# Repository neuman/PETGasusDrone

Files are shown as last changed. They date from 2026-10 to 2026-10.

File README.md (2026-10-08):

# PETGasus

A small 3D-printed quadcopter for an adult and a kid to build together. It needs no soldering, prints in one piece in PETG, and flies by sight (no camera or goggles), mostly indoors.

**[See the design explained, with a 3D build-along →](https://neuman.github.io/PETGasusDrone/)**

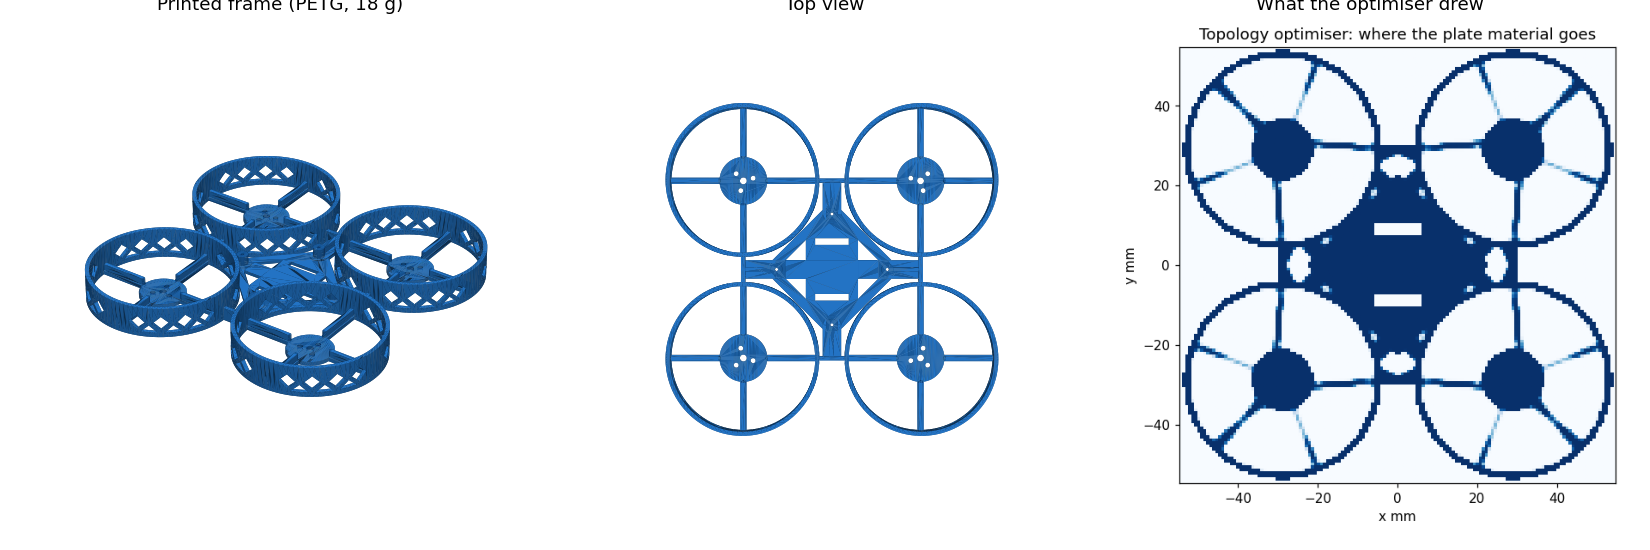
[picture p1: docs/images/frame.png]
The printed frame, its top view, and the topology optimiser's density field it was drawn from


| | |
|---|---|
| Frame | 108 × 108 × 15 mm, one PETG print, ~18 g, no supports |
| Ready to fly | ~45 g, under the FAA's 250 g registration line |
| Props | 45 mm, each spinning inside its own duct |
| Flight time | ~3.9 min per 1S 320 mAh battery (estimate) |
| Electronics | Taken from a BetaFPV Meteor75 Pro kit: plug-in motors, no soldering |
| Control | ExpressLRS radio, Betaflight flight software, self-levelling mode |
| Cost | $167 for everything, including radio, batteries and charger; $148 for the essentials |

## Build one

- **[BUILD_GUIDE.md](BUILD_GUIDE.md)** covers the shopping list, the two measurements to take before printing, print settings, assembly, radio binding, Betaflight setup and first flights.
- **Print files:** [`build/print/frame.3mf`](build/print/frame.3mf) for Snapmaker Orca, Bambu Studio or PrusaSlicer, and [`build/print/frame.stl`](build/print/frame.stl) for anything else.

## How the frame was designed

The plate that holds the motors came out of a 2.5D topology optimisation (SIMP: plate bending plus in-plane stiffness, a hover load and a crash load). The optimiser's raw field had 0.75 mm blades, which are too thin to print. So its load path was redrawn as printable ribbed spokes, and that exact printed shape was checked again with the same finite-element model.

| | Ordinary X frame | PETGasus |
|---|---|---|
| First vibration mode | 171 Hz | 282 Hz |
| Crash stiffness | 1× | ~3.5× |

The higher first mode keeps the frame away from the wobble that printed frames are known for. The reasoning, including what was tried and rejected, is in [`decisions/`](decisions/) and [`docs/decisions.md`](docs/decisions.md).

## What is proven and what isn't

Every number above comes from the model, [`model/petgasus.py`](model/petgasus.py). Each requirement is a file in [`claims/`](claims/) and has an automated check that must be able to fail. Current state:

- **Pass (simulation and geometry):** lift, weight, flight time, vibration mode, parts fit with no clashes, screws, motor wire length, printable with no supports, one piece.
- **Fail:** the $150 budget (C10). The full list is $167; it fits under $150 by skipping the optional spare props, screws and strap.
- **Assumed, not yet measured (A1–A6):** for example, how much the ducts cost in thrust, and the kit board's size.
- **Not tested on a real drone yet (P1–P5):** crash drops, hover, Betaflight setup, fit and thrust. Each test is described in its claim file and in the build guide.

## Working on the design

The checks run with [nopekit](https://github.com/neuman/nopekit).

```sh
pip install -r requirements.txt
pip install git+https://github.com/neuman/nopekit

python3 -m nopekit check --tier 1     # rebuild the model and run every check
python3 -m nopekit site build         # regenerate the project site
python3 -m nopekit site serve         # plain-language front page at site/index.html
python3 tools/run_topopt.py           # re-run the topology optimiser (~6 min)
```

Change a number in `model/petgasus.py`, then run `check`. After any model change, refresh the known-good reference with `python3 tools/freeze_known_good.py` before running `check`.

| Path | What it is |
|---|---|
| `model/` | The single source of truth: parameters, geometry (manifold3d), topology optimisation, assembly |
| `gates/` | The project's own checks; each reads its limit from a claim |
| `claims/` | What must be true, with acceptance limits and reasons |
| `selftest/` | Known-good design and known-bad fixtures every check must catch |
| `bom/` | Parts, prices and sources |
| `views/`, `site/` | The project site (`site/index.html` is the plain-language front page). Pushing `site/` to `main` publishes it to GitHub Pages |
| `.nopekit/verdicts/` | Check results, kept as evidence |

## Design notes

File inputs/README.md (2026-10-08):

# inputs/ — the evidence this design is built on

Put real files here. Hand sketches, photos of the thing you'd buy instead, CAD
you already have, datasheet PDFs, caliper readings, log files. Intake is not only
a conversation: the numbers that matter usually arrive as a photo of a napkin.

Use `nopekit ingest <path>` rather than copying by hand — it files the bytes in
the right bucket, hashes them, and writes the artifact's record,
`inputs/<id>.json`, pinning that hash so an edited input shows up as drift. Then
use `nopekit extract` to record what you actually read out of it:

    nopekit ingest inputs/sketches/hull.png --desc "midship section, dimensioned"
    nopekit extract hull-png --what "hull beam at midship reads 148 mm" \
                              --grounds beam_mm

**An artifact nobody extracted from is decoration.** A file sitting in this
directory grounds nothing, proves nothing, and will not stop anyone from
re-litigating a number two months from now. `nopekit inputs --unextracted`
lists the decorations.

## Records here, bytes in the buckets

Every top-level `inputs/*.json` is a **record** — one ingested artifact: where
its bytes are, their pinned sha256, and what was read out of them. It is read
strictly, so a stray evidence file saved as `inputs/loads.json` is refused
rather than mistaken for one. **Evidence bytes live in the bucket
subdirectories below**, never at the top level: a JSON log is evidence and goes
in `data/` or `measurements/`.

## Buckets

- `sketches/`      hand drawings, napkin diagrams, whiteboard photos
- `references/`    photos of existing products, teardowns, prior art
- `cad/`           STL, STEP, 3MF, f3d, KiCad, gerbers
- `screenshots/`   a UI, a config screen, a vendor page, another tool's output
- `datasheets/`    component and material datasheets (usually PDF)
- `specs/`         written specs, briefs, RFQs, requirements — and published
                   standards (IPC, ASTM, NEC); a standard is a requirements doc
- `measurements/`  calipers, scales, meters: numbers off the real world
- `data/`          CSV, logs, test results, and anything that fits nowhere else

The directory an artifact sits in is a hint the pipeline reads, so a photo in
`references/` is treated as prior art and the same photo in `sketches/` is
treated as your own drawing. File accordingly.

Empty buckets do not survive a `git clone` (git does not track empty
directories). `nopekit ingest` recreates whichever one it needs.

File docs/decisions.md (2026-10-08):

# Decision log

Generated by `nopekit decide` — edit the ledger, not this file.

Newest first. Every entry names what **lost** and why. That is the point: a
rejected alternative with its reason is the only thing that stops the next
person (or the next context window) re-proposing it and re-discovering the same
wall. `nopekit why <param-or-claim>` pulls one item's slice of this file.

## 2026-10-07 — Plate layout drawn from the topology optimiser

`plate-layout-drawn-from-the-topology-optimiser`

The base plate is the optimiser's load path made printable: no hub-to-motor arms; each motor seat hangs on 4 ribbed spokes (1.3 mm x 4.8 mm ribs) from its own duct ring, the hub reaches the four duct-to-duct webs on ribbed bridges, and the webs are 6 mm tall. Judged by the same 2.5D plate FE on the exact printed layout: first mode 286 Hz vs 187 Hz for the hand-drawn arms at the same webs, crash compliance 2.2x lower, for +0.8 g.

**Rejected**

- **hand-drawn arms + 3 flat spokes** — first mode 187 Hz, under C4's 200 Hz
- **optimiser density field printed directly** — its spokes were 0.75 mm blades; the 1.6 mm minimum-member clean-up deleted them and cut the motor seats loose (first mode 7 Hz)
- **5 spokes, as the optimiser drew** — thrust-to-weight 3.025: no margin on C1
- **3 spokes** — crash stiffness 0.85-1.18x the hand-drawn frame's
- **4 mm webs** — first mode 213 Hz; 6 mm gives 283 Hz for 0.12 g

**Params:** `plate_layout`, `spoke_count`, `spoke_phase_deg`, `web_h`  
**Claims:** `C4`, `C1`  
**Evidence:** `build/topopt/field.png`

---

## 2026-10-07 — Battery hangs under the hub on a strap

`battery-hangs-under-the-hub-on-a-strap`

The 1S pack lies along x under the base plate, held by one 10 mm strap through two hub slots; the strap passes over the hub under the AIO, which sits on 4.5 mm posts to make room.

**Rejected**

- **top tray on the AIO screws** — the 57 mm pack clashes with the duct walls at tray height (interference gate); clearing the duct tops needs 9.4 mm tray legs and M1.4x16 screws, and raises the CG over the props
- **deck screwed onto the duct webs** — a second print and four more screws for a kid to fumble, and the CG still sits above the prop plane

**Params:** `fc_post_h`, `strap_slot_w`  
**Claims:** `C5`

---

## 2026-10-07 — build() writes the print meshes

`build-writes-the-print-meshes`

build() generates the frame with manifold3d and writes build/print/frame.stl (content-addressed) in the same call that measures its volume, bbox and interferences, so the numbers gates read and the file the slicer reads cannot disagree.

**Rejected**

- **separate generator script** — the mesh gates would read a file whose freshness nothing checks against the model

---

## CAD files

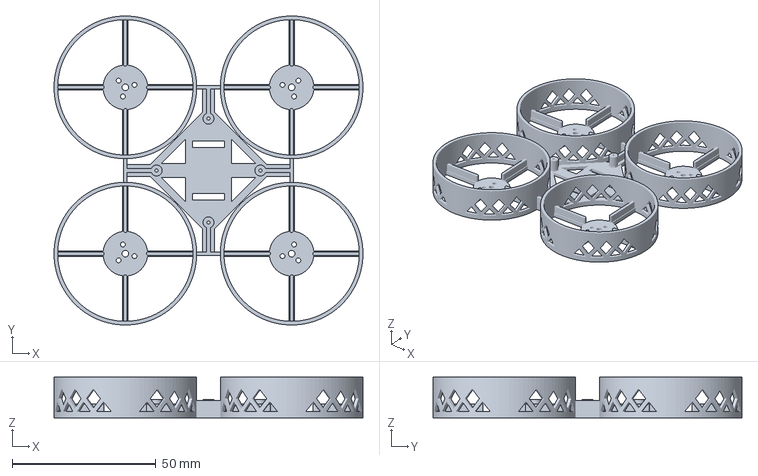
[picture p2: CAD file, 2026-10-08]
build/print/frame.3mf
107.4 x 107.4 x 14.1 mm

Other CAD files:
build/print/frame.ply
build/print/frame.stl

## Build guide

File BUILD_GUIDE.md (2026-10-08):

# PETGasus: build guide

PETGasus is a small 3D-printed quadcopter for an adult and a 10-year-old to build together. It flies by sight (no camera or goggles), mostly indoors and in a calm back yard.

| | |
|---|---|
| Size | 108 × 108 × 15 mm frame, 82 mm motor-to-motor |
| Weight | ~45 g ready to fly (under the FAA's 250 g registration line) |
| Frame | One print in PETG, about 18 g of plastic and ~1.5–2 h. No supports. |
| Soldering | None. The motors plug into the board and the battery lead is already attached. |
| Flight time | ~3.5–4 min per battery (estimate) |
| Prop guards | All four props spin inside ducts |

The frame layout came from a topology optimiser (`tools/run_topopt.py`). It tied each motor to its own duct ring with four ribbed spokes, joined the ducts to each other, and tied that ring to the centre plate. Compared with an ordinary hand-drawn "X" frame of the same footprint, it is about 3.6× stiffer in a crash. Its first vibration mode is 286 Hz against 187 Hz, which keeps it away from the wobble problem that printed frames are known for. These figures come from simulation only. The real tests are below.

---

## 1. Shopping list

Prices were checked on 2026-10-07. Re-check them before ordering.

| # | Item | Where | Price |
|---|---|---|---|
| 1 | **BetaFPV Meteor75 Pro II O4 PNP, ELRS version.** This is a parts donor. It contains the flight controller (Matrix 1S 3-in-1: FC, ESC and ELRS receiver), four 1102 motors on plugs, props, and a stock frame to fall back on if the printed one breaks. | [BetaFPV store](https://betafpv.com/products/meteor75-pro-ii-o4-brushless-whoop-quadcopter) | $79.99 |
| 2 | **BetaFPV LiteRadio 3 ELRS** radio. It also works as a USB joystick for simulators. | [BetaFPV store](https://betafpv.com/products/literadio-3-radio-transmitter) | $32.99 |
| 3 | **BetaFPV LAVA II 1S 320 mAh, BT2.0, 5-pack** | Amazon B0GJSTMT8J | $23.19 |
| 4 | **HOBBYFLY 6-port 1S USB charger (BT2.0)** | Amazon B0FHCVCC1R | $11.99 |
| 5 | Spare Gemfan 1811 45 mm 3-blade props, 1.5 mm shaft, 12-pack | BetaFPV store | $4.99 |
| 6 | M1.4 self-tapping screw assortment that includes M1.4 × 6 (you need 4) | Amazon | ~$8 (estimate) |
| 7 | 10 mm hook-and-loop battery straps | Amazon | ~$6 (estimate) |

The total is **$167**. Without items 5 to 7 it is **$148** plus shipping (see the budget note at the end).

**Why the kit instead of individual parts.** The no-solder board and the plug-in motors cost more bought separately ($80) than the whole kit. The kit's board also has no video transmitter, so there is nothing to license or burn out.

**All-Amazon alternative.** Matrix 1S 5-in-1 5A board (B0DQ8FH3VV, $47.99) plus 1102 18000KV motors (B0834P2LSY, $36.79). This costs about $7 more. That board has a video transmitter, which must stay in PIT mode with its antenna on, and a smaller 5 A ESC. Its mounting holes are 26 mm apart, not 25.5 mm, so change `fc_hole_spacing` and rebuild.

**Do not buy** the Amazon "LiteRadio 3" listing B09PV86XXY. It is the FrSky version and cannot talk to this receiver.

**Worth it later.** RadioMaster Pocket ELRS (Amazon B0CG93QM4T, ~$80 plus two 18650 cells) is a radio worth keeping as he gets better.

---

## 2. Before printing: two measurements (5 minutes)

Once the kit arrives, check two numbers with calipers. The frame was sized around them:

- **Flight controller board.** It must be **30 mm square or smaller**. If it is bigger, change `fc_board_side` in `model/petgasus.py` and rebuild. The ducts will move out to make room.
- **Motor.** It must be **14 mm diameter or less** and **13.8 mm tall or less**. The little clip on the bottom of the shaft has to fit a **2.3 mm** hole.

These are claims A3 and A4. When they check out, record them (see section 9).

---

## 3. Print

Open `build/print/frame.3mf` in Snapmaker Orca. `frame.stl` is the same part for other slicers.

For the sealed print package, run `python3 -m nopekit export print-v1` after recording A3 and A4. It writes `out/print-v1/`, which holds the mesh and a print-settings sheet.

- **PETG.** If the spool has been open a while, dry it first. Wet PETG strings inside the ducts.
- 0.4 mm nozzle, 0.2 mm layers, **3 walls**, **100% infill**.
- **No supports.** Nothing on the part needs them: the steepest overhang is 40° and there are no bridges. If the slicer adds supports, turn them off.
- **5 mm brim.** Snip it off afterwards.
- Print it flat side down, as exported.

After printing, run an M1.4 screw in and out of each of the four small posts in the middle. That pre-cuts the threads.

---

## 4. Take the kit apart

Work with the battery unplugged throughout.

1. Pull the props off. Twist gently and lift straight up.
2. Unplug the four motor connectors from the board, then unscrew the board from the stock frame. **Keep its screws.** If they are M1.4 × 4 or longer, they fit the printed posts and you can skip buying item 6.
3. Unscrew the motors from the stock frame. Each has 3 tiny M1.4 × 3 screws; keep all 12.
4. Put the stock frame and canopy in a bag. That is the spare drone.

---

## 5. Assemble

The centre plate has two strap slots, one on the left and one on the right, with their long sides running front to back. The frame is symmetric, so pick either end along the slots as the **front** and mark it with a marker.

1. **Motors.** Set each motor on a round seat with its wire pointing toward the centre. Screw it on from underneath with its three M1.4 × 3 screws. Snug is enough: these screws strip if forced.
2. **Flight controller.** Place the board on the four posts with its **arrow pointing at the front-right duct**. It sits turned 45°, so its corners point between the ducts. That is what lets it fit. Screw it down with four M1.4 screws.
3. **Motor plugs.** Plug each motor into the nearest socket. Which motor goes to which socket gets checked in Betaflight in step 7.
4. **Battery strap.** Thread the strap up through one slot, over the centre plate (under the board), and down through the other slot. The battery hangs **underneath** the frame along the front-back line. Its weight sits low, which makes the drone steadier for a beginner.
5. **Props stay off** until the Betaflight checks in step 7 are done.

**Check:** spin each motor by hand. Nothing should rub.

---

## 6. Bind the radio

The kit's receiver runs ExpressLRS (ELRS) 3.4. The LiteRadio 3 runs ELRS 3.0. They share a major version and should bind, but this pairing has not been tested.

1. Turn the radio on.
2. Plug the drone battery in and out three times quickly. The receiver LED blinks fast in bind mode.
3. Use the radio's bind function (see the LiteRadio 3 manual). The LED goes solid when bound.

---

## 7. Betaflight setup (adult; ~20 min; **props OFF**)

Install **Betaflight App** (the configurator) and plug the board into a computer over USB.

1. **Setup tab, board alignment.** Set **Yaw = 45** because the board is turned. Tilt and turn the drone in your hand. The 3D model on screen must follow exactly. If it turns the opposite way, use **−45 (315)**. Getting this wrong flips the drone on its first takeoff, so check it twice.
2. **Motors tab, battery plugged in, props off.** Use **Motor reorder** to click each motor in the order it asks. Then use **Motor direction** to make each one spin the way the diagram shows. Write down which way each one spins.
3. **Modes tab.**
   - **ARM** on a switch.
   - **ANGLE** always on, so the drone self-levels. Do not turn it off until he can hover in place for a whole battery.
   - **Flip over after crash** ("turtle") on another switch. When the drone lands upside down, this flips it back over without walking to it.
4. **Beginner limits.**
   - PID Tuning tab: **Throttle Limit = Scale, 70%**.
   - Rates: lower them so the drone feels calm.
   - Raise both as he improves.
5. **Failsafe.** Arm with props off, then switch the radio off. The motors must stop.
6. **Props on.** Each prop's leading edge must lead in the direction its motor spins. Gemfan props come in two mirror-image types; match them to the directions you wrote down. Props push down on the 1.5 mm shafts.

---

## 8. First flights

- **Practice in a simulator first**, using the radio as a USB joystick. Liftoff and VelociDrone both have a line-of-sight camera mode. A couple of evenings in the sim saves a lot of props.
- Start in a big room or a calm yard, standing behind the drone with both of you facing the same way.
- First goal: hover at knee height for 10 seconds, then land. Next: hover for a whole battery. Then fly slow squares.
- Land when the drone sags or the radio warns about low voltage. Unplug the battery as soon as it lands.

**Batteries (LiPo).** They are safe when treated well. Never charge them unattended, never charge or fly a puffy battery, and store them in a LiPo bag or metal tin. The adult does the charging.

**Rules (US).** Under 250 g and flown for fun, no registration is needed. The adult should pass the free FAA **TRUST** test and carry the certificate. Stay below 400 ft (you will be far below that) and keep the drone in sight.

---

## 9. Testing it, and recording what you find

Simulation says the design works. These tests on the real drone are what prove it. Record each result in your own terminal; it is your observation, so the AI can't record it for you. Photos make good evidence.

| Test | What to do | Pass |
|---|---|---|
| **P4** Fit | Board, motors, props and battery fitted. Spin each prop by hand. | Nothing touches |
| **P3** Setup | Betaflight checks in section 7 | All four motors in the right place and direction; 3D model follows the drone |
| **P5** Thrust | Strap the drone upside down to a kitchen scale. Motors tab, all four at 100% for 2 s. | Scale reading ≥ 3 × the drone's weight |
| **P2** Hover | Hover for 30 s at 1 m | No buzzing or wobble; motors only warm |
| **P1** Crash | Bare frame, 5 drops from 2 m onto a hard floor | No cracks or white stress marks |

```sh
export PYTHONPATH=~/.claude/plugins/cache/nopekit/nopekit/a00d0e5da19d/src
python3 -m nopekit claim physical P4 pass --evidence photos/p4.jpg --detail "props spin free"
python3 -m nopekit claim physical A4 assume     # after measuring the board
```

For the full picture of what is checked, what is assumed and what is still unknown, see `REPORT.md`, or run `python3 -m nopekit site serve`.

---

## Budget note

The full list comes to $167, against a $150 target. Ways to get under $150:

- **Skip the strap.** A rubber band holds a 1S battery fine to start with.
- **Skip the spare props.** The kit includes a set, but kids break props.
- **Skip the screws.** This works if the kit's board screws turn out to be M1.4 × 4 or longer.

With all three skipped the total is **$148 plus BetaFPV's shipping**, which is not published.

The project's budget check (claim C10) stays red until you choose: either drop lines from `bom/bom.json` or raise the budget.

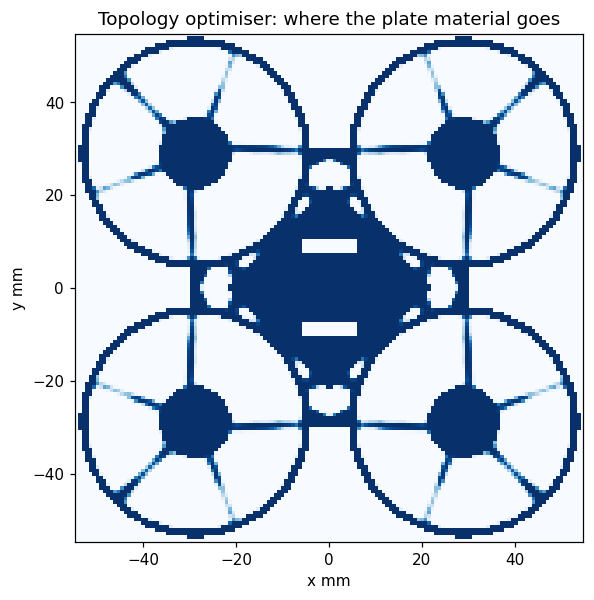
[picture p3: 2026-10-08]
build/topopt/field.png

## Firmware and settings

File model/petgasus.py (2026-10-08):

"""petgasus.py — the model: a no-solder, 3D-printed, 1S ducted micro drone.

Built by an adult and a 10-year-old together. Flown line-of-sight first (no
camera), in angle mode, indoors and in a calm back yard. Electronics are bought
(no soldering: the motors plug into the flight controller, and the battery lead
is pre-attached); the one-piece frame is printed in PETG on a
Snapmaker U1.

This file is the single source of truth (METHOD rule 1). Every printed mesh, every
mass, thrust and clearance figure, and every number a gate judges is derived from
`Config` in `build()`. Every Config field carries its reason in its docstring;
what was tried and lost is in PARAMS.

Frame: millimetres, grams, seconds. +x forward, +y left, +z up; origin on the bed
at the frame centre (z=0 is the underside of the base plate).
"""
from __future__ import annotations

import hashlib
import json
import math
import os
from dataclasses import asdict, dataclass

_HERE = os.path.dirname(os.path.abspath(__file__))
ROOT = os.path.dirname(_HERE)

PETG = {
    "density_g_mm3": 1.27e-3,
    "E_mpa": 1800.0,
    "yield_mpa": 30.0,
    # Conservative FDM modulus, not the 2000-2200 MPa coupon value: a printed arm
    # is beads and bonds, and the bonds are the soft part. The bracket reference
    # model and the fdm-print pack use the same figure.
}

G = 9.80665


@dataclass
class Config:
    """Every input. Nothing outside this dataclass is an input."""

    # --- bought parts (each grounded by a datasheet / listing; see inputs/) ---
    motor_mass_g: float = 2.85
    """g per motor, BetaFPV 1102 21000KV (2026) - the motors in the Meteor75 Pro II
    kit (vendor listing). JST1.25 3-pin plug: they plug into the AIO, no solder."""

    motor_body_d: float = 14.0
    """mm, envelope of the 1102 bell for the seat and clearance checks. The
    listing's '11 mm' is the stator; the bell is wider. ASSUMPTION until one is
    measured with calipers (claim A3 / P4)."""

    motor_h: float = 13.8
    """mm, 1102 (2026) base to shaft tip (listing)."""

    motor_hole_circle_d: float = 6.6
    """mm, 1102 mount: 3 x M1.4 on a 6.6 mm circle (vendor). Shared by most
    08xx/10xx/11xx whoop motors, so the frame takes other motors later."""

    motor_screw_clear_d: float = 1.7
    """mm, clearance for M1.4. 1.5 is the nominal free fit; FDM holes print about
    0.1-0.2 mm small, and a screw that has to be forced through cracks a 1.8 mm seat."""

    motor_screw_len: float = 3.0
    """mm, the M1.4 x 3 screws that come with the motors."""

    motor_centre_relief_d: float = 2.3
    """mm, hole under the motor for the shaft end and its C-clip. Sized by the seat,
    not the clip: the screw holes' inner edges sit 2.45 mm from the centre, and 2.3
    leaves a 1.3 mm web (3 beads, cad.wall_thickness). 3.5 lost: a 0.70 mm web.
    The clip's real size is part of A3 - if it does not clear, open the hole with a
    3 mm drill and expect C7 to flag the thinner web."""

    motor_kv: float = 21000.0
    """rpm/V, the kit's 1102 21000KV (2026)."""

    motor_thrust_max_g: float = 46.3
    """g per motor, full throttle, 1S: BetaFPV's published test of the 1102
    22000KV on a GF-1635 40 mm 3-blade. The 2026 21000KV has no published test;
    this sibling's 40 mm figure is used as a FLOOR for the kit's 45 mm props
    (a bigger disc on the same motor makes more static thrust)."""

    motor_thrust_test_v: float = 4.2
    """V of that thrust test. NOT STATED by the vendor - ASSUMPTION A6. If
    the test was at 3.7 V the real margin is ~30% better than modelled."""

    prop_d: float = 45.0
    """mm, Gemfan 1811 3-blade, 1.5 mm shaft: the props that come in the kit.
    40 mm lost: it needs a separate purchase and gives up disc area."""

    prop_mass_g: float = 0.32
    """g per prop, GF 1811 (vendor)."""

    prop_hub_drop: float = 2.5
    """mm, prop plane below the motor's top: the hub presses down onto the shaft."""

    fc_mass_g: float = 4.2
    """g, BetaFPV Matrix 1S 3-in-1 (FC + 12 A ESC + ELRS receiver), with its
    BT2.0 lead (vendor). No video transmitter: nothing to license or burn out."""

    fc_hole_spacing: float = 25.5
    """mm, Matrix 1S 3IN1 square mounting pattern (vendor: 25.5 x 25.5)."""

    fc_board_side: float = 30.0
    """mm, PCB edge, square. ASSUMPTION A4: not published; whoop boards on a
    25.5 pattern run 28-30 mm. Measure before printing."""

    fc_pcb_t: float = 1.0
    """mm, AIO board thickness, for the screw stack."""

    fc_top_components_h: float = 2.0
    """mm, tallest part on the AIO's top face; only the envelope uses it."""

    battery_mass_g: float = 8.2
    """g, BetaFPV LAVA II 1S 320 mAh LiHV, BT2.0 (vendor; Amazon B0GJSTMT8J, 5-pack)."""

    battery_l: float = 64.0
    """mm, LAVA II 320 (vendor 64 x 10 x 6)."""
    battery_w: float = 10.0
    """mm."""
    battery_h: float = 6.0
    """mm."""

    battery_mah: float = 320.0
    """mAh. 480 mAh lost: 4.4 g heavier, thrust-to-weight 2.85 against C1's
    3.0 - it still fits the strap (strap_bay_w) for longer, gentler flights."""
    battery_v_nom: float = 3.8
    """V, LiHV nominal (4.35 V full)."""

    misc_mass_g: float = 2.0
    """g, screws, strap, the FC antenna and wire. A guess with a margin in it."""

    # --- the frame ---
    plate_t: float = 1.8
    """mm, base plate, arms and motor seats. 9 layers at 0.2: three solid top and
    bottom layers either side of a core. The motor's own M1.4 x 3 screws must
    still reach 1 mm into the motor through it (claim C9)."""

    arm_w: float = 5.0
    """mm, arm width at plate level."""

    rib_w: float = 1.3
    """mm, the stiffening rib along each arm: 3 beads of 0.42."""

    rib_h: float = 3.0
    """mm above the plate. Stiffness goes as h^3, so this rib is most of the arm's
    bending stiffness; it stops below the motor seat so it never meets a prop."""

    spoke_w: float = 2.0
    """mm, flat flange under each spoke's rib (5 beads). The rib carries the
    bending; 2.5 lost: 0.3 g for nothing the FE could see."""

    prop_tip_gap: float = 1.0
    """mm, radial gap prop tip to duct wall. Under ~0.75 a 1 mm print error or a
    bent prop strikes; over ~2 the duct stops helping thrust."""

    duct_wall: float = 1.3
    """mm, 3 beads at 0.42 mm: the fdm min-wall rule."""

    duct_above_prop: float = 1.0
    """mm of duct above the prop plane: the lip that fingers and furniture meet
    before the tips. 3.0, 2.0 and 1.5 lost: 0.8, 0.5 and 0.25 g for no safety a kid
    would notice - the ring around the tips is the guard."""

    duct_lattice: bool = True
    """Below the prop band the duct wall is a 45-degree diamond lattice. A solid
    wall made the ducts ~14 g, over half the frame (see PARAMS)."""

    lattice_overhang_deg: float = 40.0
    """Steepest lattice window edge, degrees from vertical: 5 under the 45 deg
    no-support rule, so slicer rounding never lands a face on the wrong side of it."""

    lattice_above_members: bool = False
    """Start the lattice above the tallest member that joins the duct, instead of
    above the plate with solid patches where members join."""

    joint_margin: float = 0.4
    """mm of solid duct wall kept either side of a spoke or web where it joins the
    duct (no window there). One strut width (1.3) lost: 0.9 g of extra wall."""

    lattice_margin: float = 0.4
    """mm of solid wall between the plate's top face and the lattice (2 layers)."""

    lattice_strut_w: float = 1.3
    """mm, lattice strut width square to the strut: 3 beads, same rule as the wall."""

    duct_band_below_prop: float = 2.0
    """mm of solid duct wall below the prop plane, where the tips run (the
    sweep is +-1.5 mm). 3.0 lost: 0.7 g, which put thrust-to-weight under 3.0 once the
    lattice's flat-ceiling half-cells were taken out."""

    foot_w: float = 1.3
    """mm, flange at each duct's foot. Equal to the wall, i.e. no flange: a
    5 mm brim does the bed-adhesion job and is snipped off; a flange stays and weighs."""

    web_h: float = 6.0
    """mm, height of the wall joining neighbouring ducts. The cheapest stiffness
    in the frame: 4.0 -> 6.0 took the first mode from 213 to 283 Hz for 0.12 g, because
    the duct ring IS the structure in the spoked layout."""

    fc_yaw_deg: float = 45.0
    """The AIO is mounted turned 45 degrees so its corners point between the ducts
    rather than into them; that is worth ~6 mm of wheelbase. Betaflight then needs
    board alignment yaw = 45 (build guide step, physical claim P3)."""

    fc_post_od: float = 3.8
    """mm, printed posts the AIO sits on. 3.6 lost: 1.25 mm of wall round the 1.1 mm
    pilot, under the 1.26 mm process minimum (cad.wall_thickness)."""

    hub_t: float = 1.4
    """mm, the hub plate under the AIO: 7 layers at 0.2. It carries the battery
    strap and shields the board, not the arm loads. 1.2 lost: under the 1.26 mm
    process minimum (cad.wall_thickness), and 1.3 is not a whole number of layers."""

    min_member_w: float = 1.6
    """mm, narrowest optimised member that gets printed (4 beads). Narrower ones
    are removed from the extracted outline, not printed as threads. 2.0 lost: at
    the hub-excluded budget the optimiser's deep members are ~1.5 mm blades, and
    the open deleted them - seats came loose, first mode 7 Hz."""

    hub_holes: bool = True
    """Four triangular lightening holes in the hub, clear of the strap and posts."""

    hub_hole_margin: float = 2.5
    """mm of hub plate kept round each lightening hole (bars to the posts, strap
    path, rim). 3.0 lost: 0.1 g, after phasing the duct lattice for the wire ports
    cost 0.26 g."""

    hub_margin: float = 1.2
    """mm of plate around each FC post in the hub outline. 1.5 lost: 0.1 g
    the strap and the posts did not need."""

    fc_post_h: float = 4.5
    """mm above the plate. The battery strap runs over the hub UNDER the AIO, so
    this is strap_t plus 3 mm for the AIO's bottom-side parts. 3.0 lost: it left
    1.5 mm, and the strap would press on the ESC's FETs."""

    fc_pilot_d: float = 1.1
    """mm, pilot for an M1.4 screw threading into PETG."""

    fc_screw_len: float = 6.0
    """mm, M1.4 x 6 screws down through the AIO into the posts (claim C8)."""

    fc_board_clear: float = 1.0
    """mm minimum between the AIO's edge and any duct wall, in plan."""

    strap_t: float = 1.5
    """mm, thickness of a hook-and-loop strap where it laps over the hub."""
    strap_w: float = 10.0
    """mm, a 10 mm hook-and-loop battery strap."""

    strap_bay_w: float = 16.0
    """mm between the strap slots' inner edges: the widest pack the strap straddles
    (LAVA II 480 is 15.5 wide), so the 320 and the 480 both fit."""

    strap_slot_w: float = 2.2
    """mm, slot across the strap's thickness: 1.5 strap + print shrink + fumbling."""

    # --- bought-part shapes, for the assembly view and the clearance check ---
    # Listing values where one is published; otherwise a stated envelope.
    motor_base_d: float = 11.0
    """mm, the 1102's stator mount/base (listing: '11 mm', the stator size)."""
    motor_base_h: float = 2.0
    """mm, base height below the bell. Envelope (A3)."""
    shaft_d: float = 1.5
    """mm, 1102 shaft (listing)."""
    shaft_exposed: float = 5.0
    """mm of shaft above the bell (listing: shaft length 5 mm)."""
    motor_lead_len: float = 37.0
    """mm, the 1102 (2026)'s lead to its plug (listing: 37 mm cable)."""
    lead_d: float = 1.2
    """mm, a motor lead's 3 x 30 AWG wires bundled."""
    prop_hub_d: float = 5.0
    prop_blades: int = 3
    prop_chord: float = 6.0
    prop_blade_t: float = 0.8
    prop_pitch_deg: float = 12.0
    """GF 1811 3-blade, drawn: hub, three flat pitched blades. Shape for the view;
    the clearance it is checked for is its swept disc and the blade corners."""
    fc_hole_d: float = 1.6
    """mm, the AIO's mounting holes (M1.4 clearance). Assumed."""
    socket_w: float = 4.5
    socket_depth: float = 3.0
    socket_h: float = 2.5
    """mm, a JST 1.25 3-pin motor socket on the AIO's top face, at the edge facing
    its motor. Position assumed; P4 checks the board that arrives."""
    screw_d: float = 1.4
    screw_head_d: float = 2.6
    screw_head_h: float = 0.8
    """mm, M1.4 pan-head screws."""
    bt20_len: float = 6.5
    bt20_w: float = 5.0
    bt20_h: float = 4.0
    """mm, one half of a BT2.0 plug pair."""

    # --- the printer and the process ---
    bed_x_mm: float = 270.0
    """mm, Snapmaker U1 build plate X (user: 270 mm bed)."""
    bed_y_mm: float = 270.0
    """mm, Snapmaker U1 build plate Y."""
    bed_z_mm: float = 270.0
    """Snapmaker U1 build volume (user: 270 mm bed)."""

    brim_mm: float = 5.0
    """mm of brim per side: the duct rims touch the bed on a 1.3 mm wall; a brim
    keeps them down and is snipped off."""
    nozzle_d_mm: float = 0.4
    """mm, the U1's stock nozzle."""
    extrusion_width_mm: float = 0.42
    """mm, 1.05 x nozzle - a stock profile's line width; 3 of them is the wall rule."""
    layer_height_mm: float = 0.2
    """mm, 0.2: half the nozzle, the PETG default; plate_t and hub_t are whole layers."""
    perimeters: int = 3
    """Wall loops. Every thin wall here is designed as exactly 3 of them."""
    infill_fraction: float = 1.0
    """Thin walls everywhere: there is no room for infill; treat as solid."""
    print_speed_mm_s: float = 60.0
    """mm/s nominal; an ordinary PETG speed (the estimate derates it)."""
    max_print_time_h: float = 3.0
    """An afternoon with a 10-year-old: a print that runs overnight is a print he
    does not see."""
    max_filament_g: float = 1000.0
    """g, one spool: the frame uses ~2% of it."""

    # --- flight ---
    duct_thrust_factor: float = 0.9
    """Static thrust with the duct relative to the open-prop test. Tight ducts can
    add 10-20%; a printed duct with a 1 mm gap and no shaped lip is assumed to
    cost 10% instead. ASSUMPTION (A1)."""

    hover_eff_g_per_w: float = 3.0
    """g of thrust per electrical watt at hover. ASSUMPTION (A2): typical of 0802
    class motors on 40 mm props; refine from a blackbox log of a real hover."""

    usable_capacity_frac: float = 0.8
    """Land at ~3.5 V/cell: 80% of rated capacity, kinder to cheap 1S packs."""

    # --- topology optimisation of the plate layout (model/topopt.py) ---
    plate_layout: str = "spoked"
    """'arms' = the hand-drawn first layout (hub-to-motor arms, 3 flat spokes);
    'spoked' = the layout the topology optimiser found (see geometry.members and
    tools/run_topopt.py). 'arms' lost: first mode ~160 Hz against C4's 200."""

    spoke_count: int = 4
    """Spokes per motor seat. The optimiser drew 5; 5 lost: 0.6 g more for a
    thrust-to-weight of 3.025 - no margin on C1. 3 lost: crash stiffness 0.85-1.18x the
    hand-drawn frame's."""

    spoke_phase_deg: float = 45.0
    """Angle of the first spoke from the seat-to-centre direction. 45 (spokes
    on the diagonals of the seat) lost nothing; 0 (one spoke straight at the hub, one
    straight out) gave the same mode and half the crash stiffness (1.0x vs 2.2x)."""

    bridge_w: float = 4.0
    """mm, flat flange under each hub-to-web bridge's rib. 6.0 lost: 0.1 g for
    4 Hz of first mode."""


    topopt_h: float = 0.75
    """mm, FE grid size. 0.5 halves the error and quadruples the run time."""

    topopt_rmin: float = 2.0
    """mm, density-filter radius: the optimiser's length scale. 1.6 lost: with
    projection it drew members under 1 mm wide."""

    prop_block_mm: float = 3.6
    """mm of equivalent depth charged per mm^2 of plate under a prop, on top of its
    mass: blocking downwash costs like 2 x plate_t of material. Replaced
    'prop_area_cost = 3' (a multiplier on mass), which starved every spoke."""

    bounce_g: float = 1.0
    """g of vertical acceleration on the fixed masses for the bending load case.
    The problem is linear, so the value only scales compliance; 1 g keeps it readable."""

    crash_load_n: float = 20.0
    """N, a hit on a duct rim (in-plane). ~ the quad at 4 m/s stopping in ~10 ms."""

    topopt_w_thrust: float = 1.0
    """Objective weight on bounce stiffness (the vibration mode); see topopt_w_crash."""
    topopt_w_crash: float = 4.0
    """Objective weights: bounce stiffness (the vibration mode) vs. crash stiffness.
    2:1 for bounce lost: mode 434 Hz but crash stiffness fell to 0.31x the hand-drawn
    frame's, and a 10-year-old's drone is mostly a crash-test article."""

    topopt_iters: int = 120
    """Optimiser iterations: 20 per projection-sharpness step (beta 1..16), then
    until it stops moving."""

    topopt_member_h: float = 4.8
    """mm, height of an optimised member: plate_t + rib_h, the baseline rib's
    height, so the two layouts are compared at the same depth. A flat 1.8 mm
    optimised plate lost: bending stiffness goes as depth cubed, and the first
    run's flat layout bounced at 116 Hz against the ribbed baseline's 217."""

    member_clear: float = 1.0
    """mm a deep member keeps from the motor's base and from the AIO footprint,
    where the plate stays plate_t thin (motor seat; strap path under the board)."""

    topopt_mass_frac: float = 1.0
    """Optimised plate mass as a fraction of the baseline plate's."""

    topopt_smooth: float = 0.4
    """mm, corner rounding on the extracted outline; also deletes slivers < 0.8 mm."""

    prop_sweep_half_h: float = 1.5
    """mm, half-height of the band the prop occupies, for the clearance check."""


CONFIG = Config()


PARAMS = [
    {"name": "fc_yaw_deg", "units": "deg", "rejected": [
        {"value": "0 deg", "why": "AIO corners point into the ducts; wheelbase grows ~6 mm to clear them"}]},
    {"name": "prop_tip_gap", "units": "mm", "rejected": [
        {"value": "0.5 mm", "why": "inside one print error plus prop flex of a strike"}]},
    {"name": "duct_lattice", "units": "bool", "rejected": [
        {"value": "solid duct wall", "why": "~14 g of ducts: frame 20.5 g, thrust-to-weight 2.2"},
        {"value": "6 small diamond windows", "why": "took 0.3 g out; not worth the print time"},
        {"value": "round windows", "why": "their tops are bridges/overhangs that need support"}]},
]


# --------------------------------------------------------------------------- #
def _derive_layout(c: Config) -> dict:
    d: dict = {}
    d["prop_r"] = c.prop_d / 2
    d["duct_r_in"] = d["prop_r"] + c.prop_tip_gap
    d["duct_r_out"] = d["duct_r_in"] + c.duct_wall
    d["prop_z"] = c.plate_t + c.motor_h - c.prop_hub_drop
    d["duct_h"] = d["prop_z"] + c.duct_above_prop
    d["mount_r"] = c.motor_body_d / 2 + 0.75

    # FC posts and the board, turned by fc_yaw_deg
    yaw = math.radians(c.fc_yaw_deg)
    h = c.fc_hole_spacing / 2
    d["fc_post_xy"] = [
        (round(sx * h * math.cos(yaw) - sy * h * math.sin(yaw), 4),
         round(sx * h * math.sin(yaw) + sy * h * math.cos(yaw), 4))
        for sx, sy in ((1, 1), (1, -1), (-1, -1), (-1, 1))]

    # Motor offset a (motors at (+-a, +-a)) is DERIVED: the smallest a at which the
    # AIO board and its posts clear every duct by fc_board_clear. Board corners and
    # edge midpoints are the extreme points of a square; checking those plus the
    # posts is exact for a square against a circle centred on the diagonal.
    s = c.fc_board_side / 2
    pts = []
    for sx, sy in ((1, 1), (1, -1), (-1, -1), (-1, 1), (1, 0), (-1, 0), (0, 1), (0, -1)):
        pts.append((sx * s * math.cos(yaw) - sy * s * math.sin(yaw),
                    sx * s * math.sin(yaw) + sy * s * math.cos(yaw), c.fc_board_clear))
    for (px, py) in d["fc_post_xy"]:
        pts.append((px, py, c.fc_post_od / 2 + c.fc_board_clear))

    def worst(a):
        return min(math.hypot(px - a, py - a) - d["duct_r_out"] - r for (px, py, r) in pts)
    # an edge midpoint is not the closest point of an edge to the circle in general:
    # sample the board outline densely as well, so the answer holds for any yaw
    for k in range(400):
        t = k / 400 * 4
        side, f = int(t), t - int(t)
        corners = [(s, s), (s, -s), (-s, -s), (-s, s)]
        (x0, y0), (x1, y1) = corners[side], corners[(side + 1) % 4]
        x, y = x0 + (x1 - x0) * f, y0 + (y1 - y0) * f
        pts.append((x * math.cos(yaw) - y * math.sin(yaw), x * math.sin(yaw) + y * math.cos(yaw),
                    c.fc_board_clear))
    lo, hi = d["duct_r_out"], 200.0
    for _ in range(60):
        mid = (lo + hi) / 2
        if worst(mid) >= 0:
            hi = mid
        else:
            lo = mid
    d["motor_offset"] = round(hi + 0.05, 2)
    d["fc_duct_clearance_mm"] = round(worst(d["motor_offset"]) + c.fc_board_clear, 3)
    d["wheelbase_mm"] = round(2 * math.sqrt(2) * d["motor_offset"], 2)
    d["duct_gap_mm"] = round(2 * d["motor_offset"] - 2 * d["duct_r_out"], 2)

    # rib stops at the motor seat's edge
    arm_len = math.sqrt(2) * d["motor_offset"]
    d["rib_end_frac"] = (arm_len - d["mount_r"]) / arm_len

    # arm section (plate strip + rib, parallel axis) - the arm's bending stiffness
    A1, z1 = c.arm_w * c.plate_t, c.plate_t / 2
    A2, z2 = c.rib_w * c.rib_h, c.plate_t + c.rib_h / 2
    zc = (A1 * z1 + A2 * z2) / (A1 + A2)
    d["arm_I_mm4"] = round(c.arm_w * c.plate_t ** 3 / 12 + A1 * (z1 - zc) ** 2
                           + c.rib_w * c.rib_h ** 3 / 12 + A2 * (z2 - zc) ** 2, 4)
    d["arm_area_mm2"] = A1 + A2
    d["arm_zc"] = zc
    d["strap_slot_y"] = round(c.strap_bay_w / 2 + c.strap_slot_w / 2, 2)
    d["strap_slot_len"] = c.strap_w + 1.0
    return d


def _mesh_props(man) -> dict:
    mesh = man.to_mesh()
    import numpy as np
    v = np.asarray(mesh.vert_properties)[:, :3]
    lo, hi = v.min(axis=0), v.max(axis=0)
    return {"volume_mm3": round(man.volume(), 2), "area_mm2": round(man.surface_area(), 2),
            "bbox_mm": [round(float(x), 3) for x in (hi - lo)], "lo": [float(x) for x in lo]}
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

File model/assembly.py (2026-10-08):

"""assembly.py - every part of the drone, placed where it goes, for the 3D view and
for the clearance check (claim C5).

Same frame as geometry.py: millimetres, +x forward, +z up, z=0 under the base
plate. The printed frame comes from geometry.frame; everything else here is a
BOUGHT part, drawn at the size its listing gives (or, where none is published, at
the conservative envelope the model already assumes - see A3/A4). These are not
CAD of the vendor's parts: they are the space each one takes, shaped enough to be
recognisable and measured exactly enough to be checked against the frame.

Each part: name -> dict(solid=Manifold, color=(r, g, b), explode=(dx, dy, dz),
group=str). `explode` is the direction it comes off in the assembly order: the
battery and strap drop away below, the motor screws below the seats, the motors,
the board and its screws lift off above, the props last of all.
"""
from __future__ import annotations

import math

import manifold3d as m3d

import geometry_petgasus as geo

C_FRAME = (255, 122, 26)      # orange PETG
C_PCB = (24, 96, 52)
C_CHIP = (30, 30, 34)
C_SOCKET = (235, 235, 225)
C_MOTOR = (150, 150, 165)
C_BELL = (110, 70, 170)
C_PROP = (230, 50, 60)
C_BATT = (95, 45, 165)
C_STRAP = (28, 28, 28)
C_SCREW = (190, 190, 200)
C_WIRE = (35, 35, 35)
C_RED = (205, 35, 35)


def _tube(points, d, seg=16):
    """A wire: a chain of cylinders with ball joints through `points` (x, y, z)."""
    r = d / 2
    parts = [m3d.Manifold.sphere(r, seg).translate(p) for p in points]
    for p0, p1 in zip(points, points[1:]):
        v = [b - a for a, b in zip(p0, p1)]
        L = math.sqrt(sum(x * x for x in v))
        if L < 1e-6:
            continue
        # cylinder along +z, rotated onto v
        tilt = math.degrees(math.acos(max(-1.0, min(1.0, v[2] / L))))
        yaw = math.degrees(math.atan2(v[1], v[0]))
        parts.append(m3d.Manifold.cylinder(L, r, r, seg).rotate((0, tilt, 0))
                     .rotate((0, 0, yaw)).translate(p0))
    return m3d.Manifold.batch_boolean(parts, m3d.OpType.Add)


def polyline_len(points):
    return sum(math.dist(a, b) for a, b in zip(points, points[1:]))


def _screw(x, y, z_head_top, length, head_d, head_h, shank_d, up=True):
    """M1.4 pan-head screw. `up`: head on top, shank down (else head below, shank up)."""
    if up:
        head = geo._cyl(head_h, head_d / 2, z_head_top - head_h)
        shank = geo._cyl(length, shank_d / 2, z_head_top - head_h - length)
    else:
        head = geo._cyl(head_h, head_d / 2, z_head_top - head_h)
        shank = geo._cyl(length, shank_d / 2, z_head_top)
    return (head + shank).translate((x, y, 0))


def motor_lead_route(c, d, mx, my):
    """The 3-wire lead from the motor's base, out through the duct's port window,
    to the AIO socket on the board edge that faces this motor. Points (x, y, z).

    Returns (points, socket_xyz). The port window is the full lattice cell the
    duct is phased to put on its hub side (geometry._duct port_deg).
    """
    u = (-mx / math.hypot(mx, my), -my / math.hypot(mx, my))       # toward the hub
    lat = geo.lattice(c, d)
    pcb_top = c.plate_t + c.fc_post_h + c.fc_pcb_t
    z_lead = pcb_top + c.socket_h / 2                                 # socket entry height
    if lat:                                                           # ...inside the window?
        zc, qv = lat["z0"] + lat["hl"] / 2, lat["qv"]
        z_lead = min(z_lead, zc + 0.5 * qv)
    z_base = c.plate_t + c.motor_base_h / 2
    r_base = c.motor_base_d / 2 + c.lead_d / 2 + 0.05
    dist = math.hypot(mx, my)
    sock_r = c.fc_board_side / 2                                      # board edge, from centre
    p = [
        (mx + r_base * u[0], my + r_base * u[1], z_base),
        (mx + (r_base + 3) * u[0], my + (r_base + 3) * u[1], z_base),
        (mx + (d["duct_r_in"] - 2) * u[0], my + (d["duct_r_in"] - 2) * u[1], z_lead),
        (mx + (dist - sock_r - 0.2) * u[0], my + (dist - sock_r - 0.2) * u[1], z_lead),
    ]
    return p, (-u[0] * sock_r, -u[1] * sock_r, z_lead)


def parts(c, d, frame):
    out = {}

    def add(name, solid, color, explode, group, step):
        out[name] = dict(solid=solid, color=color, explode=explode, group=group, step=step)

    # `step` is the assembly order the build guide follows: 1 the printed frame,
    # 2 motors and their screws, 3 the flight controller and its screws, 4 the motor
    # leads plugged in, 5 the battery, its strap and the power plug, 6 the props.
    add("frame", frame, C_FRAME, (0, 0, 0), "printed", 1)

    # --- the AIO: PCB on the posts, turned fc_yaw_deg, with its parts ---
    z_pcb = c.plate_t + c.fc_post_h
    pcb_top = z_pcb + c.fc_pcb_t
    yaw = c.fc_yaw_deg
    pcb = geo._box(c.fc_board_side, c.fc_board_side, c.fc_pcb_t, z0=z_pcb)
    hole = c.fc_hole_spacing / 2
    for sx in (1, -1):
        for sy in (1, -1):
            pcb = pcb - geo._cyl(c.fc_pcb_t + 2, c.fc_hole_d / 2, z_pcb - 1).translate((sx * hole, sy * hole, 0))
    chip = geo._box(7, 7, 1.0, z0=pcb_top)
    fets = m3d.Manifold.batch_boolean(
        [geo._box(3, 3, 0.8, cx=sx * 6, cy=sy * 6, z0=z_pcb - 0.8) for sx in (1, -1) for sy in (1, -1)],
        m3d.OpType.Add)
    board = (pcb + chip + fets).rotate((0, 0, yaw))
    sockets = []
    for (mx, my) in geo.motor_centres(d):
        _, (sx_, sy_, _z) = motor_lead_route(c, d, mx, my)
        ang = math.degrees(math.atan2(sy_, sx_))
        sockets.append(geo._box(c.socket_depth, c.socket_w, c.socket_h, z0=pcb_top)
                       .translate((math.hypot(sx_, sy_) - c.socket_depth / 2, 0, 0)).rotate((0, 0, ang)))
    add("flight_controller", board, C_PCB, (0, 0, 30), "electronics", 3)
    add("motor_sockets", m3d.Manifold.batch_boolean(sockets, m3d.OpType.Add), C_SOCKET, (0, 0, 30),
        "electronics", 3)

    # --- AIO screws: down through the board into the posts ---
    for i, (px, py) in enumerate(d["fc_post_xy"]):
        add(f"fc_screw_{i + 1}", _screw(px, py, pcb_top + c.screw_head_h, c.fc_screw_len,
                                       c.screw_head_d, c.screw_head_h, c.screw_d, up=True),
            C_SCREW, (0, 0, 46), "screws", 3)

    # --- motors, their screws, props, leads ---
    names = ("front_left", "front_right", "back_left", "back_right")
    bell_z0 = c.plate_t + c.motor_base_h
    bell_top = c.plate_t + c.motor_h - c.shaft_exposed
    leads_needed = {}
    for name, (mx, my) in zip(names, geo.motor_centres(d)):
        toward = math.degrees(math.atan2(-my, -mx))
        base = geo._cyl(c.motor_base_h, c.motor_base_d / 2, c.plate_t)
        bell = geo._cyl(bell_top - bell_z0, c.motor_body_d / 2, bell_z0)
        shaft = geo._cyl(c.motor_h - c.motor_base_h, c.shaft_d / 2, c.plate_t + c.motor_base_h)
        add(f"motor_{name}", (base + bell + shaft).translate((mx, my, 0)), C_BELL, (0, 0, 20), "motors", 2)
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
